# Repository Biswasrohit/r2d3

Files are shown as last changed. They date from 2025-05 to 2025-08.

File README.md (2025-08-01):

# R2D3: Dual-Axis Solar Tracker Inspired by R2D2

A proof-of-concept solar tracker that automatically orients a photovoltaic panel in two axes (azimuth & elevation) to maximize sunlight exposure. Built with an Arduino Uno, hobby servos, a solar panel sensor, and custom PLA-printed parts modeled in SolidWorks.

---

## 📖 Table of Contents

1. [Project Overview](#project-overview)  
2. [Key Features](#key-features)  
3. [Hardware Components](#hardware-components)  
4. [Software & Firmware](#software--firmware)  
5. [CAD & 3D Prints](#cad--3d-prints)  
6. [Getting Started](#getting-started)  
7. [Usage](#usage)  
8. [Results & Performance](#results--performance)  
9. [Future Improvements](#future-improvements)  
10. [References](#references)  
11. [License](#license)  

---

## Project Overview

This project implements a compact, dual-axis solar tracker that:

- **Senses** sunlight intensity using a small solar panel as both a sensor and energy source.  
- **Adjusts** panel orientation in real time via two servo motors (one for horizontal rotation, one for vertical tilt).  
- **Locks** onto the brightest direction using a dynamic, local‐scan algorithm—no full 180° sweep on each update.  
- **Demonstrates** how mechanical design, electronics integration, and firmware must co-evolve in a hands-on engineering build.

Inspired by the droid **R2D2**, our “R2D3” tracker combines playful form with practical function.

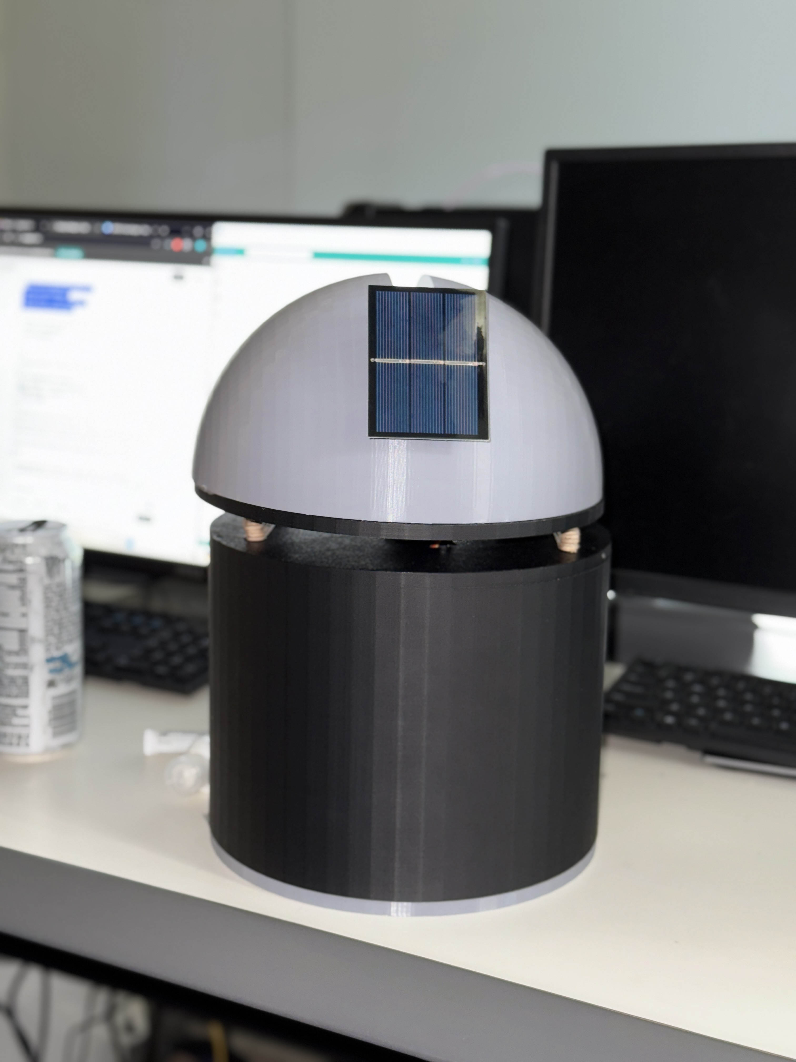
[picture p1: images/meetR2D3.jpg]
R2D3


---

## Key Features

- **Dual-Axis Control**: Independent azimuth & elevation tracking.  
- **Analog Feedback**: Reads voltage from the panel (A0) to detect light intensity.  
- **Dynamic Local Scan**: Reduces scan range for faster, more efficient tracking.  
- **PLA 3D-Printed Enclosure**: Renewable polylactic acid parts customized in SolidWorks.  
- **Modular Design**: Clear separation between electronics housing and moving head.

---

## Hardware Components

| Component | Qty  | Notes |
|---|:----:|---|
| Arduino Uno R3 | 1 | Main controller |
| Servo motor (horizontal) | 1 | 180° range, ~2 kg·cm torque |
| Servo motor (vertical) | 1 | 180° range, ~2 kg·cm torque |
| Mini solar panel (sensor)  | 1 | Outputs analog voltage proportional to light |
| PLA filament | — | Polylactic acid for 3D prints |
| Jumper wires & connectors  | — | Power, ground, data routing |
| USB-A cable | 1 | For Arduino power & programming |
| Popsicle sticks & glue | — | Quick alignment fix for print tolerances |

> **Note:** PLA stands for **polylactic acid**, a biodegradable thermoplastic derived from renewable resources.

---

## Software & Firmware

- **Arduino Sketch**  
  - `readVoltage()`: Reads and maps panel voltage (A0 → 0–5 V).  
  - `findMaxPosition()` / `trackLightLocally()`: Local-scan routines to find the brightest “hotspot.”  
  - Safety checks to prevent over-rotation beyond physical limits.

- **Dependencies**  
  - Arduino IDE (v1.8+) or Arduino CLI  
  - No external libraries required (uses core Servo & Arduino APIs)

---

## 3D Prints

- **SolidWorks Models**  
  - `CAD/StorageCube.SLDPRT` – Electronics housing with wiring pass-through  
  - `CAD/UpperSphere.SLDPRT` – Rotating head to support the panel  
  - `CAD/Base.SLDPRT` – Base
  - `CAD/TopLid.SLDPRT` - Top Lid

> **Tip:** Print at 0.2 mm layer height with 20% infill for a balance of strength and speed.

---

## Getting Started

Follow these steps to set up and run your R2D3 solar tracker:

1. **Clone the repository**  
    git clone https://github.com/Biswasrohit/r2d3.git                 
    cd r2d3

3. **3D-print the parts**  
    - Slice the files in STL/ with your preferred slicer  
    - Recommended settings: PLA, 0.2 mm layer height, 20 % infill, 60 °C bed, 200 °C nozzle

4. **Assemble the hardware**  
    - Secure the horizontal servo into LowerBase.stl  
    - Thread wiring through the base passthrough hole  
    - Attach the secondary cylindrical base and upper hemisphere (UpperHemisphere.stl) to the horizontal horn  
    - Mount the vertical servo and solar panel in the hemisphere using the popsicle-stick armature

5. **Wire the electronics**  
    - Power servos from Arduino 5 V & GND; signal pins to D9 (horizontal) and D10 (vertical)  
    - Connect panel’s positive lead to A0 and negative lead to GND  
    - Tidy cables through built-in channels

6. **Upload the firmware**  
    - Open firmware/R2D3_Tracker.ino in the Arduino IDE (v1.8+)  
    - Select “Arduino Uno” and the correct serial port  
    - Click “Upload”

7. **Power and test**  
    - Plug Arduino into USB-A (PC or power bank)  
    - Observe initial local scan, then place under a lamp or sunlight—panel should smoothly follow the brightest spot

---

## Usage

- **Initial Scan:** On power-up, performs a limited sweep around last known position to find the brightest direction  
- **Continuous Tracking:** Every 5 seconds (configurable in firmware), updates azimuth/elevation within a ±30° “hotspot” zone  
- **Safety Limits:**  
    - Azimuth: –90° to +90°  
    - Elevation: 25° to 155°

Modify these ranges in `trackAzimuth()` and `trackElevation()` to suit your hardware.

---

## Results & Performance

- **Dual-Axis Operation:** Azimuth (±90°) and elevation (25–155°) confirmed  
- **Response Time:** < 2 s to reorient within a 30° hotspot  
- **Accuracy:** Typically within 10–15° of peak illumination  
- **Robustness:** Maintains lock under partial occlusion and changing light

Full data and graphs in docs/FinalReport.pdf.

---

## Future Improvements

1. **Higher-Torque Actuators**  
   Swap to geared or brushless servos for larger panels  
2. **Custom PCB**  
   Integrate power regulation and cleaner signal routing  
3. **Refined CAD**  
   Realign parts to eliminate shim workarounds  
4. **IoT Telemetry**  
   Add an ESP32 for remote monitoring, data logging, and web dashboard  
5. **Weatherproofing**  
   Design sealed enclosures for outdoor deployment

---

## References

- Arduino® UNO R3 Product Reference Manual  
- Banerjee, R. (2015). *Solar tracking system*. IJSRP, 5(3).  
- Deekshith, K. et al. (2015). *Solar tracking system*. IJSER, 6(9).  
- Zhang, Y., Li, X., & Wang, J. (2024). *Advancements in renewable energy technologies*. Renewable Energy Reports, 10(2), 123–145.

---

## License

This project is released under the **MIT License**. See LICENSE for details.

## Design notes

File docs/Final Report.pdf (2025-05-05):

## Experimental Techniques in Engineering and Physics

## Final Report

## Azhar Ahmed & Rohit Biswas

04/29/25

Azhar Ahmed, Rohit Biswas | 1

## R2D3: Solar Tracker Inspired by R2D2

### Abstract

This report presents the full lifecycle of a dual-axis solar tracker designed to maximize

photovoltaic efficiency by maintaining optimal orientation to sunlight. Inspired by the form of

R2D2, the system integrates an Arduino Uno, servo motors, a solar panel for light sensing, and

custom polylactic acid (PLA) 3D-printed housing. Early stages focused on SolidWorks modeling

and mechanical layout, followed by iterative refinement to accommodate component fit,

movement clearance, and wiring. During assembly, torque limitations and alignment issues

prompted structural changes, including the addition of a secondary base and a simplified

mounting armature. Electrical setbacks, including unstable USB-C connections and overheating

adapters, led to system-level debugging and a hardware shift to a USB-A PC environment. A

dynamic analog feedback algorithm was implemented and successfully used to detect sunlight

intensity and drive the tracker’s dual-axis adjustment. Despite structural imperfections, the final

build achieved stable, functional tracking and fulfilled the project's engineering and design

objectives.

### I – Introduction

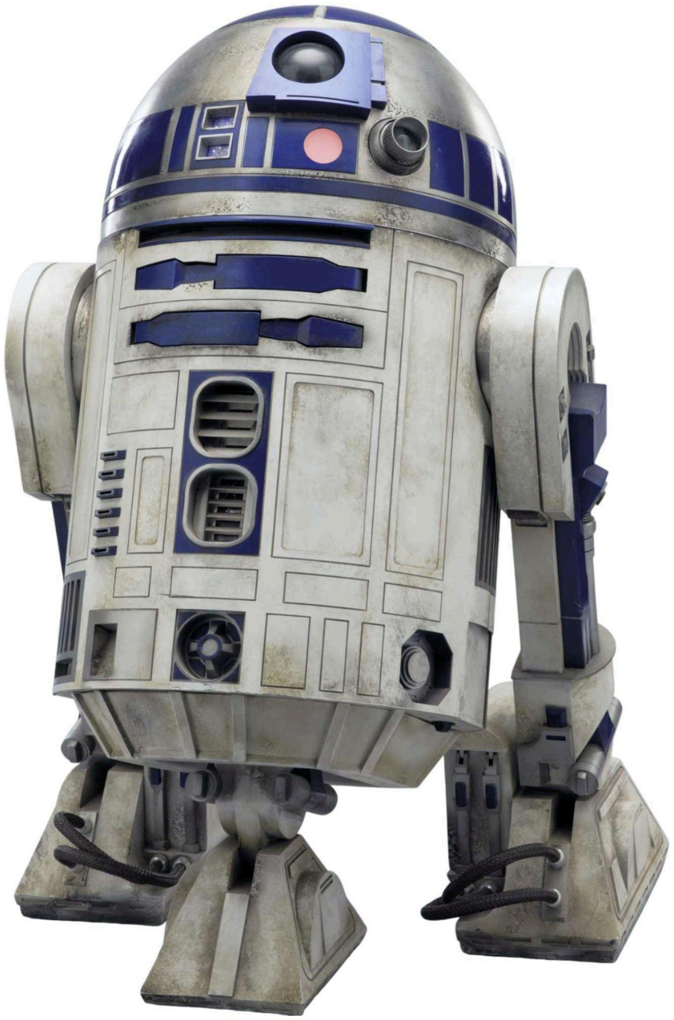
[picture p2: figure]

Solar tracking technologies enhance photovoltaic efficiency by

maintaining optimal panel orientation to sunlight. In this project, we aimed

to develop a compact, dual-axis solar tracker using an Arduino Uno, servo

motors, and a 3D-printed structure. The project was inspired by the iconic

R2D2 form, as shown in the figure above, aiming for both functionality and

design clarity.

Azhar Ahmed, Rohit Biswas | 2

The tracker was designed to adjust both azimuth and elevation using servo motors, with

inputs taken from a solar panel acting as a directional light sensor. We used SolidWorks for the

mechanical design and PLA, a biodegradable thermoplastic derived from renewable resources,

for 3D printing the components. The project proceeded through multiple design phases, starting

with sketches, followed by progressive CAD modeling, physical prototyping, and software

integration.

### II – Work Performed

### 2.1 Initial Concept & Modeling

Our initial design was built around a circular

base with a rectangular cube housing for electronics and

a hemisphere, as shown to the right, to support the solar

panel and vertical servo. We initially considered using

light-dependent resistors (LDRs) for sensing, but

ultimately chose to rely on a solar panel as both the

sensing and tracking unit.

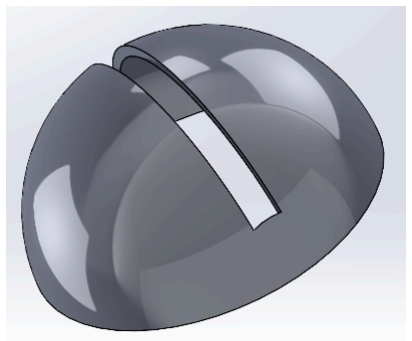
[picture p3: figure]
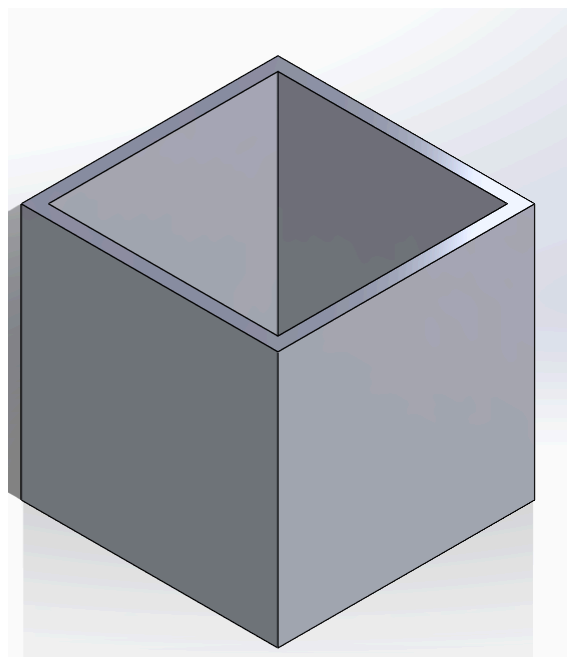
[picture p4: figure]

We translated early sketches into SolidWorks, culminating in a

structurally complete model. The lower storage cube to the right was

designed to be 150 mm x 150 mm x 120 mm, with 16 mm walls and

internal spacing to house the Arduino, battery pack, and wiring. The

hemisphere included a slit for solar panel placement and cutouts for

servo arm clearance.

Azhar Ahmed, Rohit Biswas | 3

### 2.2 Fabrication Adjustments and Secondary Base Design

Upon receiving our 3D prints, several unexpected design issues arose. The horizontal

motor struggled to rotate the full upper assembly, including the hemisphere. To reduce the torque

load, we introduced a secondary cylindrical base mounted on top of the horizontal servo motor,

which allowed only the hemisphere to rotate. A 1-inch passthrough

hole was drilled in this new base to maintain wiring continuity from the

top.

However, this modification led to two alignment issues: the

vertical motor within the hemisphere was not precisely centered, and

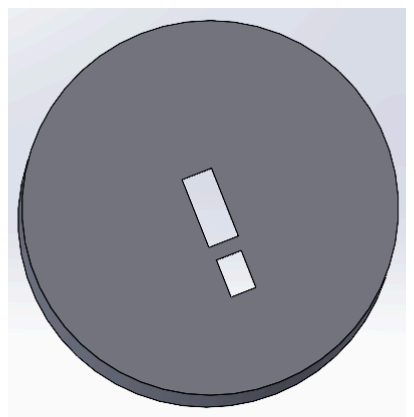
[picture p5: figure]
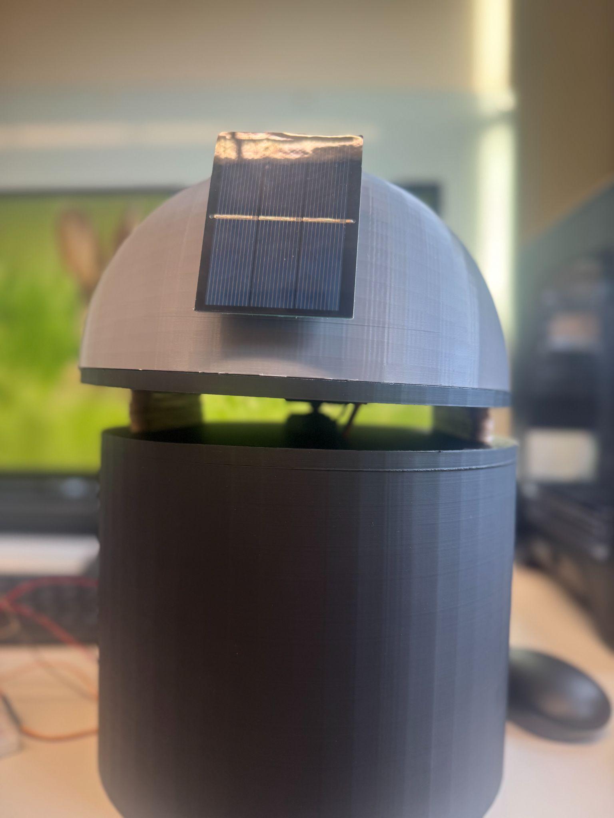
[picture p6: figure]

the horizontal motor in the upper lid to the right was slightly misaligned. This

created a noticeable tilt in the final structure. Due to limited time and printing

capacity at the university's Lite Center, we chose to proceed without

reprinting the corrected parts. To adjust for the misalignment, we added

popsicle stick stacks to keep it stable, as shown to the right.

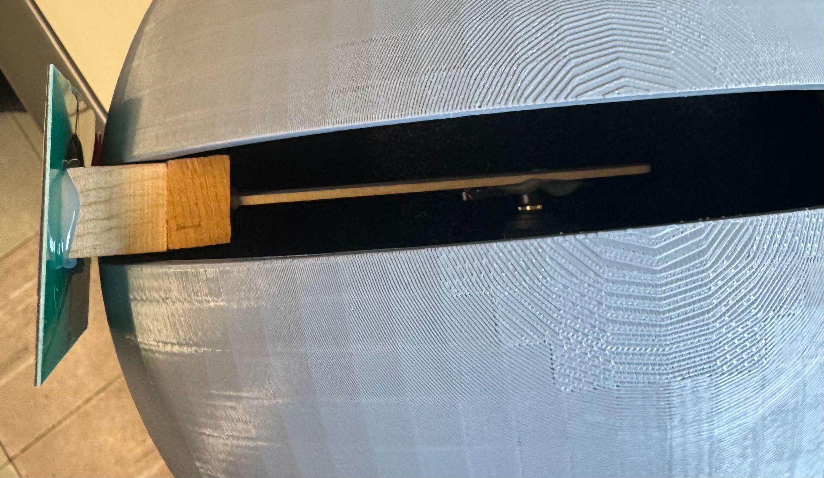
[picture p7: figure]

To connect the solar panel, we attached a standard servo horn to

a popsicle stick armature as shown to the right. The arm was glued to a

milled wooden connector. This formed a basic pivot arm to support

vertical panel movement.

### 2.3 Electrical Integration

Electrical integration included the Arduino Uno, two servo motors,

jumper wires, and the solar panel. A key issue arose with code uploading: when

using MacBooks with USB-C to USB-A adapters as shown to the right, the

Arduino failed to connect. Further investigation revealed the adapter was

Azhar Ahmed, Rohit Biswas | 4

overheating due to back current from the Arduino. Switching to a PC with native USB-A to

USB-mini B connectivity resolved the issue.

The wiring was otherwise stable, and all power and signal lines were routed through

pass-through holes in the housing. The circuit diagram below is what we used to configure our

model:

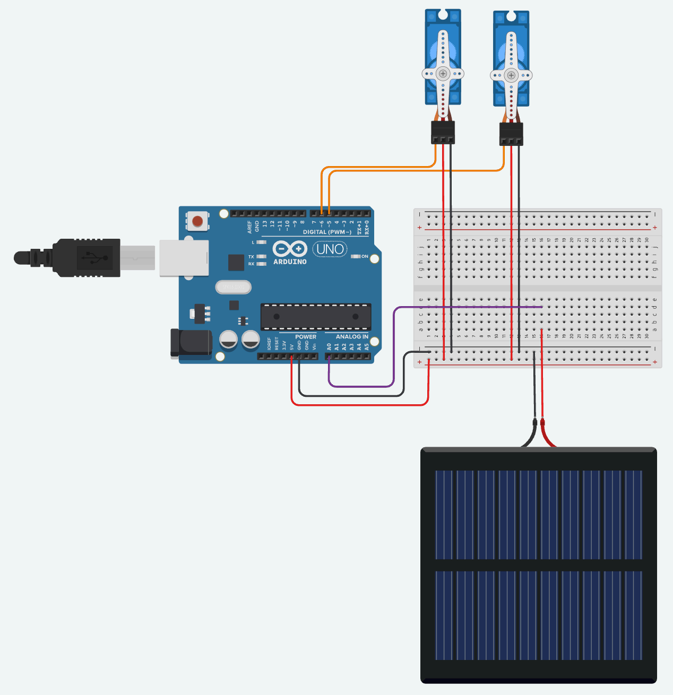
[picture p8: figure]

All elements of the circuit are wired in series, with the exception of the power terminal

from the panel being connected to the analog pin (A0) on the Arduino to read the voltage. The

analog signals will vary depending on the detection of the light, in particular, the light source

intensity; if the intensity is greater, the Arduino would read a lower voltage compared to the 5V

steady state reading, signaling light incident on the panel.

### 2.4 Software Development and Revisions

Our code below reads data from the solar panel to detect the direction of strongest light

and adjusts the servo motors accordingly. Horizontal motion is managed by the motor housed in

Azhar Ahmed, Rohit Biswas | 5

the lower cube, while vertical tilt is managed by the motor within the upper hemisphere. The

control uses PWM signals for smooth transitions and includes logical safeguards to avoid

over-rotation.

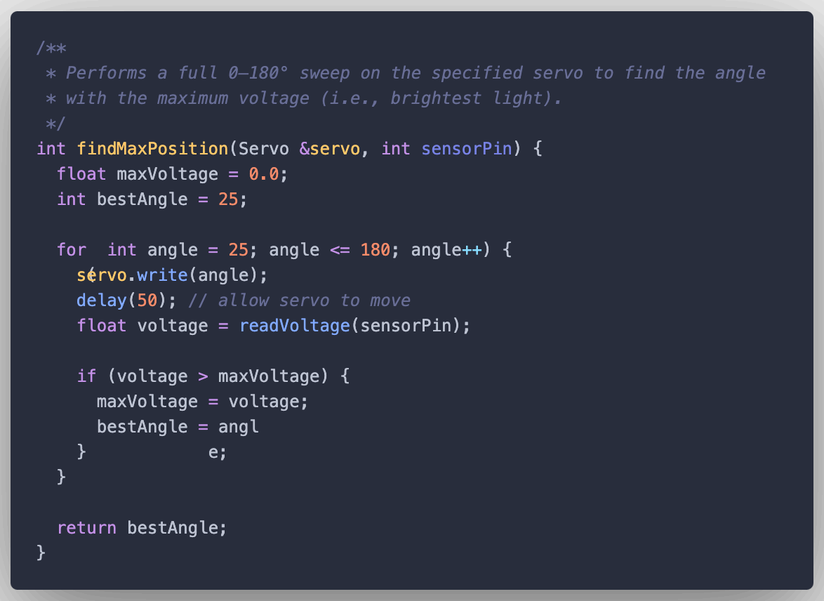
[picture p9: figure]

The readVoltage() function in the code above is the main component, as it is defined

below. This helper function reads in the analog voltage from the A0 pin on the Arduino and

translates it to intelligible values by multiplying by 5.0 / 1023.0.

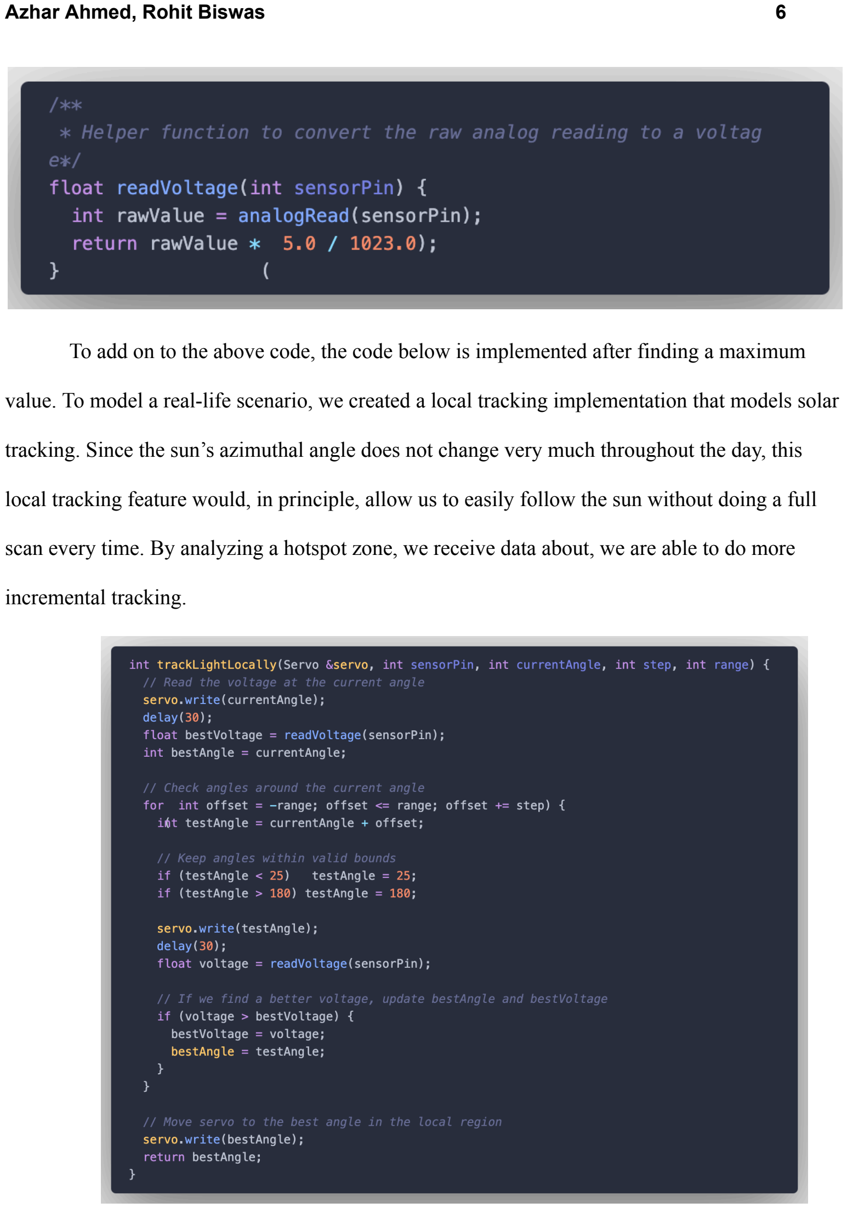
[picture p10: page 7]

Azhar Ahmed, Rohit Biswas | 6

To add on to the above code, the code below is implemented after finding a maximum

value. To model a real-life scenario, we created a local tracking implementation that models solar

tracking. Since the sun’s azimuthal angle does not change very much throughout the day, this

local tracking feature would, in principle, allow us to easily follow the sun without doing a full

scan every time. By analyzing a hotspot zone, we receive data about, we are able to do more

incremental tracking.

Azhar Ahmed, Rohit Biswas | 7

The code below puts the new dynamic tracking method to use, as we loop through the

horizontal and vertical zones, we want to get our hotspot values to then dynamically track light.

In other words, instead of scanning a full 180 degrees on each update, the system now targets

movement within a smaller range based on recent light positions. This reduces memory usage

and increases responsiveness, mimicking realistic solar tracking behavior more closely.

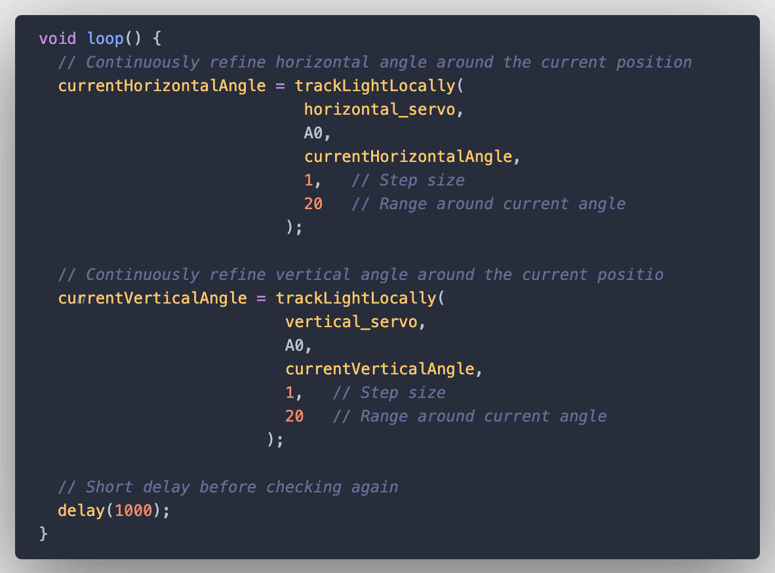
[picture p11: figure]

In addition to this unique strategy, we also made some finer adjustments to our code that

are of importance based on our mechanical design:

- Adjusted the initial zero point to 25° on the vertical servo to avoid physical collisions

with the base.

Azhar Ahmed, Rohit Biswas | 8
- Increased delays between motor movements to stabilize the structure before each reading.

### III – Results

The completed tracker successfully demonstrated dual-axis functionality. Despite

structural misalignments, the system:

- Could rotate horizontally and vertically
- Detected brighter light sources and reoriented accordingly
- Showed stable operation with the scanning algorithm

Limitations include:

- Tilted vertical axis due to off-center mounting
- Uneven weight distribution from the secondary base

Still, the system operated within expectations for a proof-of-concept prototype.

### IV – Conclusions and Future Considerations

This project highlighted the interdependence of mechanical design, electrical stability,

and coding strategy. From SolidWorks modeling to real-world assembly, every phase required

adaptation and refinement.

Critical lessons include:

- Align mechanical parts precisely to reduce system strain
- Account for motor torque limitations in early design
- Test all USB connectivity options before relying on adapters
- Build software that tolerates physical imperfections

Future improvements could include:

- Using geared or brushless servos for stronger rotation

Azhar Ahmed, Rohit Biswas | 9
- Integrating a PCB for neater and more reliable wiring
- Redesigning the base for better weight distribution

The final build, while imperfect, fulfilled the initial goal of building a functioning

dual-axis tracker and provided a robust learning experience in engineering problem-solving,

prototyping, and integration.

### References

Arduino® UNO R3 product reference manual. Retrieved from Arduino Documentation

Banerjee, R. (2015). Solar tracking system. International Journal of Scientific and

Research Publications, 5(3), 1–7. Retrieved from

https://www.ijsrp.org/research-paper-0315/ijsrp-p3923.pdf

Deekshith K., Aravind D., Nagaraju H., Reddy B. (2015). Solar tracking system.

International Journal of Scientific & Engineering Research, 6(9), 994–995. Retrieved

from https://www.ijser.org/researchpaper/SOLAR-TRACKING-SYSTEM.pdf

Zhang, Y., Li, X., & Wang, J. (2024). Advancements in renewable energy technologies:

A comprehensive review. Renewable Energy Reports, 10(2), 123–145.

https://doi.org/10.1016/j.rer.2024.01.016

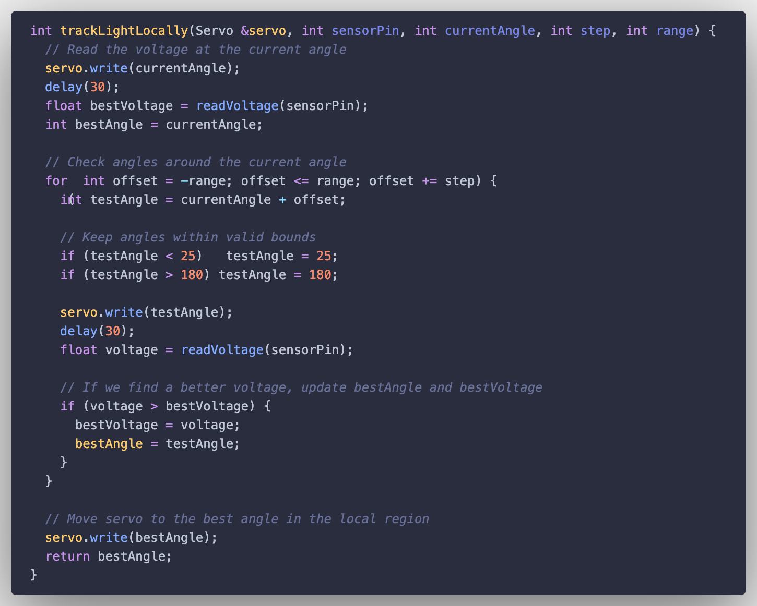
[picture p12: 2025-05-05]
images/trackLightLocally.png

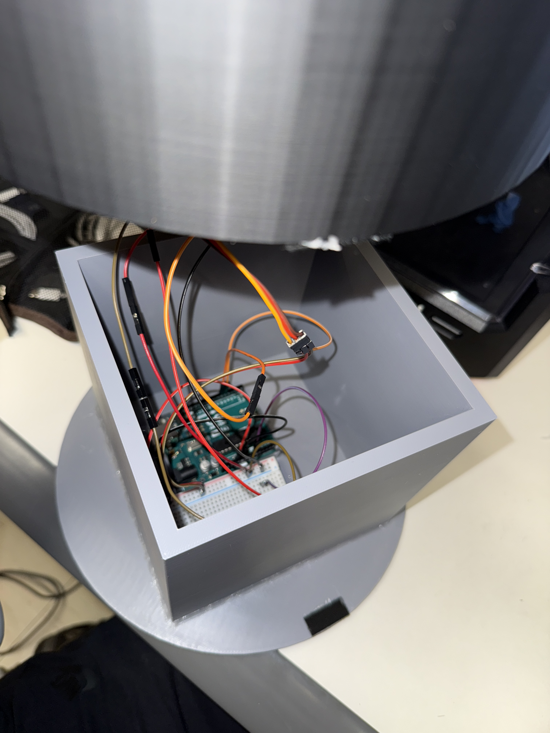
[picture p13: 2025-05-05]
images/bottomHousing.JPG

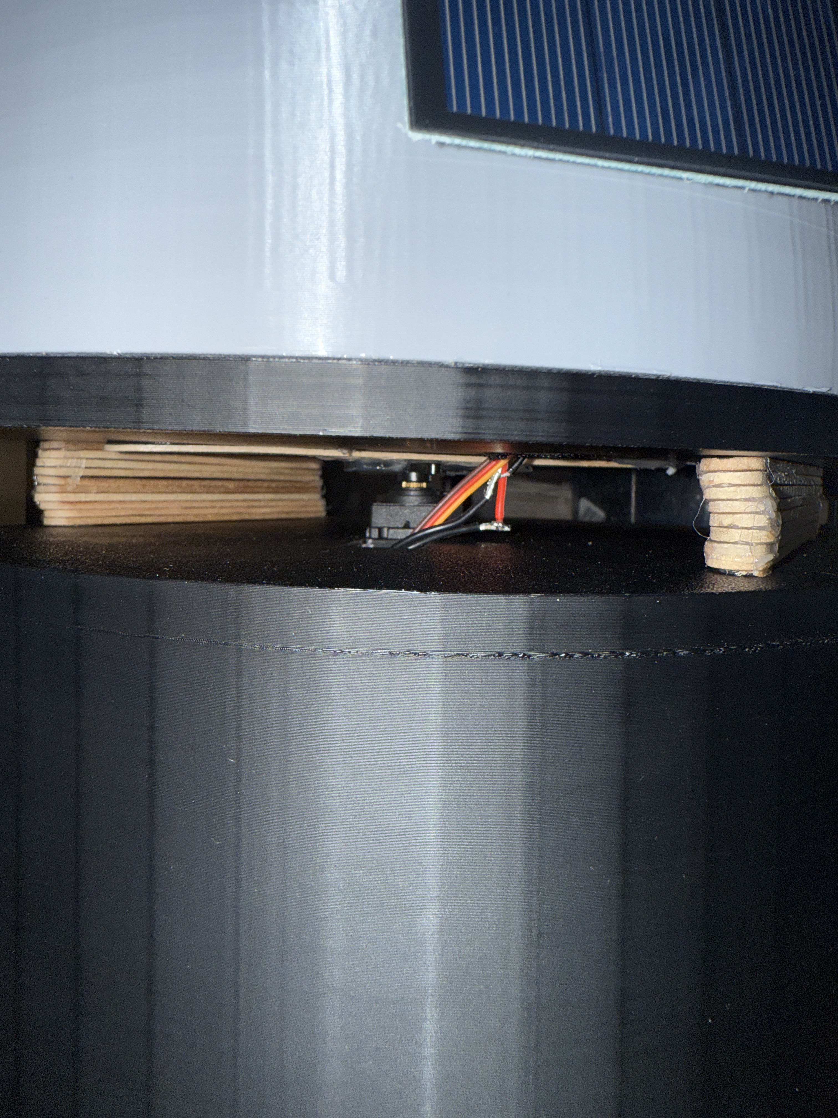
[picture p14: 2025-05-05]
images/movementMechanism.JPG

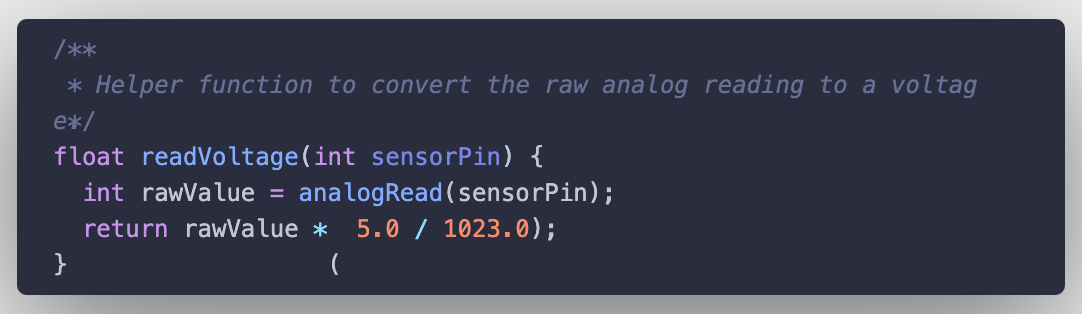
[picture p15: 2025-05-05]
images/readVoltage.png

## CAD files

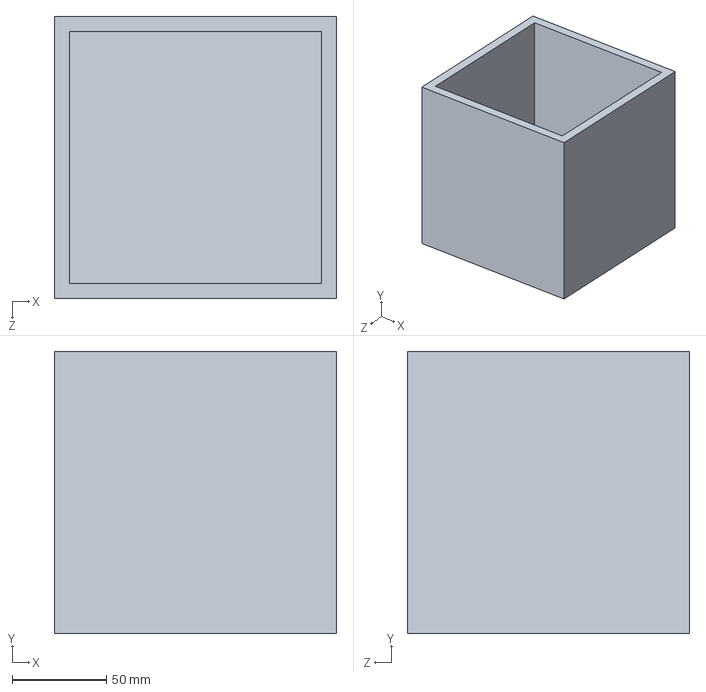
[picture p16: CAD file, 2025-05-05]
cad/Storage Cube.SLDPRT
150.0 x 150.0 x 150.0 mm

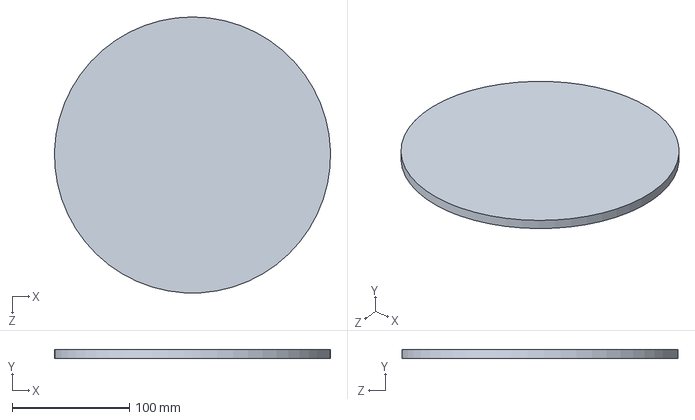
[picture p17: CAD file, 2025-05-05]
cad/Base.SLDPRT
235.9 x 8.00 x 236.0 mm

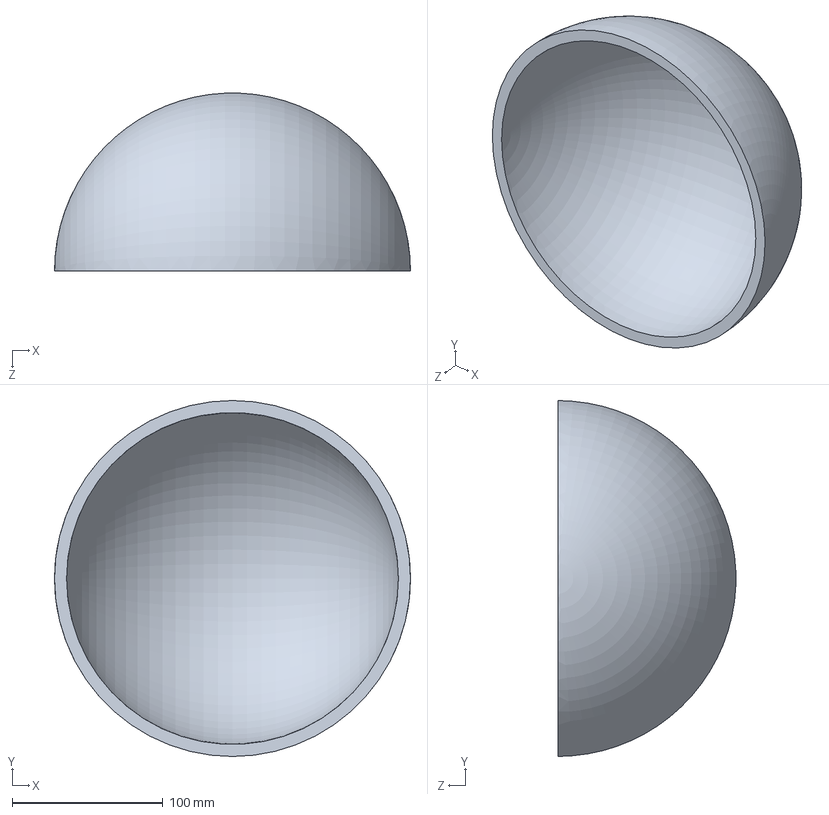
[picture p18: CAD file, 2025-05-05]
cad/Upper Sphere SLDPRT.SLDPRT
236.0 x 236.0 x 117.8 mm

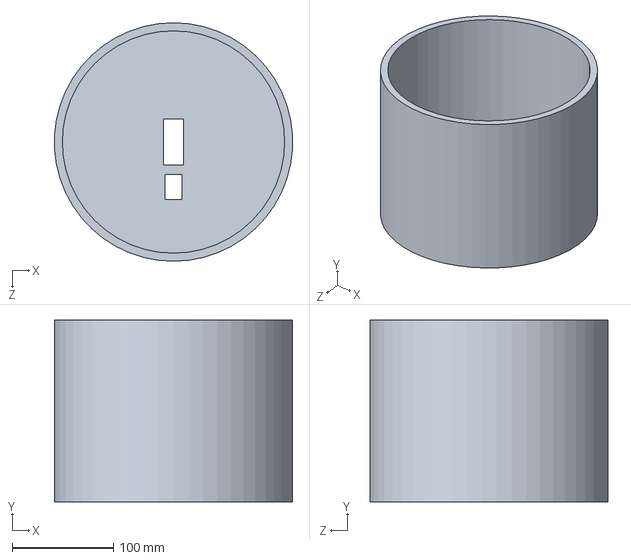
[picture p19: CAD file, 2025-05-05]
cad/Top Lid.SLDPRT
235.5 x 180.0 x 236.0 mm

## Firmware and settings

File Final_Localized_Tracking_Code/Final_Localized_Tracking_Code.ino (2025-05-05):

/*
  ROHIT BISWAS & AZHAR AHMED
  EXPERIMENTAL TECHNIQUES
  LIGHT DETECTION SOFTWARE
*/

#include <Servo.h>

// Create Servo objects for horizontal and vertical axes
Servo horizontal_servo;
Servo vertical_servo;

// Store the current angles for horizontal and vertical
int currentHorizontalAngle = 0;
int currentVerticalAngle   = 20;

void setup() {
  Serial.begin(9600);
  horizontal_servo.attach(5);
  vertical_servo.attach(6);

  // Perform an initial full sweep to find the best horizontal angle
  currentHorizontalAngle = findMaxPosition(horizontal_servo, A0);
  horizontal_servo.write(currentHorizontalAngle);
  delay(1200);

  // Perform an initial full sweep to find the best vertical angle
  currentVerticalAngle = findMaxPosition(vertical_servo, A0);
  vertical_servo.write(currentVerticalAngle);
  delay(1200);
}

void loop() {
  // Continuously refine horizontal angle around the current position
  currentHorizontalAngle = trackLightLocally(
                            horizontal_servo,
                            A0,
                            currentHorizontalAngle,
                            1,   // Step size
                            20   // Range around current angle
                          );

  // Continuously refine vertical angle around the current position
  currentVerticalAngle = trackLightLocally(
                          vertical_servo,
                          A0,
                          currentVerticalAngle,
                          1,   // Step size
                          20   // Range around current angle
                        );

  // Short delay before checking again
  delay(1000);
}

/**
 * Performs a full 0–180° sweep on the specified servo to find the angle
 * with the maximum voltage (i.e., brightest light).
 */
int findMaxPosition(Servo &servo, int sensorPin) {
  float maxVoltage = 0.0;
  int bestAngle = 25;

  for (int angle = 25; angle <= 180; angle++) {
    servo.write(angle);
    delay(50); // allow servo to move
    float voltage = readVoltage(sensorPin);

    if (voltage > maxVoltage) {
      maxVoltage = voltage;
      bestAngle = angle;
    }
  }

  return bestAngle;
}

/**
 * Looks around the current angle in a small +/- range to see if there's
 * a brighter spot nearby. Returns the new best angle found.
 */
int trackLightLocally(Servo &servo, int sensorPin, int currentAngle, int step, int range) {
  // Read the voltage at the current angle
  servo.write(currentAngle);
  delay(50);
  float bestVoltage = readVoltage(sensorPin);
  int bestAngle = currentAngle;

  // Check angles around the current angle
  for (int offset = -range; offset <= range; offset += step) {
    int testAngle = currentAngle + offset;

    // Keep angles within valid bounds
    if (testAngle < 25)   testAngle = 25;
    if (testAngle > 180) testAngle = 180;

    servo.write(testAngle);
    delay(50);
    float voltage = readVoltage(sensorPin);

    // If we find a better voltage, update bestAngle and bestVoltage
    if (voltage > bestVoltage) {
      bestVoltage = voltage;
      bestAngle = testAngle;
    }
  }

  // Move servo to the best angle in the local region
  servo.write(bestAngle);
  return bestAngle;
}

/**
 * Helper function to convert the raw analog reading to a voltage.
 */
float readVoltage(int sensorPin) {
  int rawValue = analogRead(sensorPin);
  return rawValue * (5.0 / 1023.0);
}
